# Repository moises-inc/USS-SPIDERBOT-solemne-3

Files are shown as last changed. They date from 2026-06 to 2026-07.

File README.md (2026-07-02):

# USS SpiderBot — Robot Cuadrúpedo de Reconocimiento y Rescate





**USS SpiderBot** es un prototipo de robot cuadrúpedo articulado de 4 grados de libertad (4-DoF) controlado de forma inalámbrica por una ESP32 y desarrollado bajo un modelo de programación asíncrona en **MicroPython**. El robot está diseñado para operar en entornos hostiles de búsqueda y rescate, detectando obstáculos e inestabilidades físicas de forma inteligente en el borde (Edge AI) y empleando una estructura cinemática simplificada y de bajo consumo.

---

<p align="center">
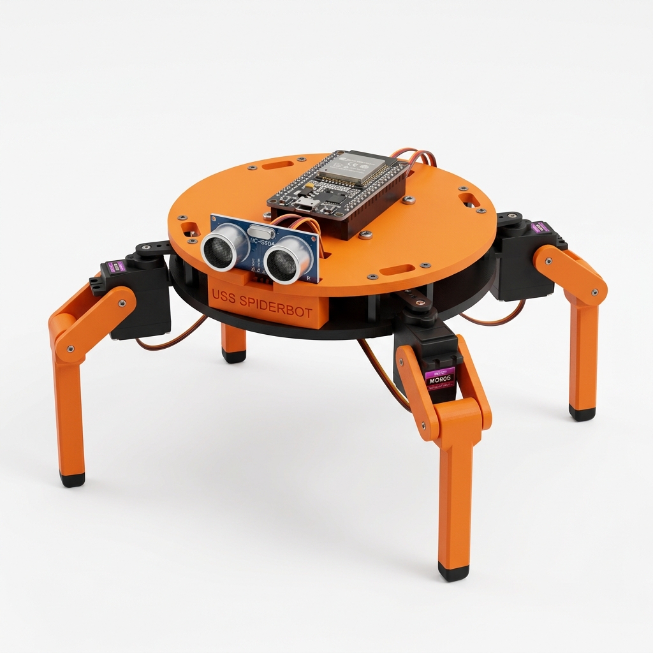
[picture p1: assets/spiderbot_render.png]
USS SpiderBot Render 3D
  
</p>

---

## 📄 Documentación y Entregables del Proyecto
Toda la fundamentación teórica, análisis físico y guías se encuentran compilados en formato PDF dentro del repositorio:
*   📚 **[Informe Técnico Final (PDF)](docs/informe_proyecto_spiderbot.pdf):** Documento formal con todo el desglose metodológico, cálculos de torque y diagramas.
*   📊 **[Presentación de Defensa Beamer (PDF)](docs/presentacion_hall_spiderbot.pdf):** Diapositivas oficiales preparadas para la exposición en el Hall de la Universidad.
*   📐 **[Guía de Modelado y CAD en OpenSCAD (PDF)](docs/guia_openscad.pdf):** Manual de desarrollo paramétrico de piezas e impresión 3D.
*   🛠️ **[Reporte de Diseño e Integración 3D (Markdown)](docs/reporte_evaluacion_diseno_3d.md):** Evaluación física y geométrica para el montaje de los nuevos componentes.

---

## 🛠️ Arquitectura de Hardware y Potencia (4-DoF Simplificada)
El diseño electrónico final prioriza la ligereza física y la eficiencia en el consumo de corriente, operando con una fuente de alimentación común estabilizada:

*   **Lógica de Control:** ESP32 DevKit V1 (38 pines) + IMU MPU6050 + Sensor de ultrasonido HC-SR04 + Zumbador activo de 5V (GPIO 14).
*   **Actuación:** 4 servomotores SG90 / MG90S conectados de forma directa a la ESP32 (sin multiplexor PCA9685).
*   **Alimentación Común Regulada (1x LM2596):**
    *   **Pack Baterías (2x 18650 Li-ion, 7.4V) ➔ LM2596 (Ajustado a 5.2V):** Un solo convertidor regulador que suministra 5.2V estables en paralelo tanto a la ESP32 (pin Vin) como a los rieles de potencia de los 4 servomotores de caderas.
    *   *Nota:* Para mitigar caídas de tensión (brownouts) por los picos de corriente, el firmware realiza un encendido secuencial espaciado por software.

### 📌 Mapa de Conexiones Físicas (Pinout)

| GPIO ESP32 | Componente | Tipo de Señal | Descripción |
| :--- | :--- | :--- | :--- |
| **GPIO 21** | MPU6050 (IMU) | SDA (I2C) | Bus de datos serie de la unidad inercial (100kHz). |
| **GPIO 22** | MPU6050 (IMU) | SCL (I2C) | Bus de reloj serie de la unidad inercial (100kHz). |
| **GPIO 18** | HC-SR04 (Sonar) | TRIGGER | Salida digital de pulso de disparo. |
| **GPIO 19** | HC-SR04 (Sonar) | ECHO | Entrada digital de pulso de retorno. |
| **GPIO 14** | Buzzer Activo | Salida Digital | Señal de alarma en caso de proximidad. |
| **GPIO 23** | Servo FR - Coxa | Salida PWM | Articulación cadera delantera derecha (Canal 0). |
| **GPIO 17** | Servo FL - Coxa | Salida PWM | Articulación cadera delantera izquierda (Canal 1). |
| **GPIO 15** | Servo RL - Coxa | Salida PWM | Articulación cadera trasera izquierda (Canal 2). |
| **GPIO 13** | Servo RR - Coxa | Salida PWM | Articulación cadera trasera derecha (Canal 3). |
| **Vin (ESP32)** | LM2596 Out | Alimentación | Tensión de entrada regulada (5.2V). |
| **GND (Unificado)** | Todo el sistema | Tierra común | Referencia negativa común unificada. |

---

## 🧠 Inteligencia Artificial Sensorial y Failsafe Embebido
El robot incorpora un módulo de Edge AI local en MicroPython ([classifier_ia.py](firmware/classifier_ia.py)) que procesa las firmas inerciales de la IMU para clasificar el estado dinámico del cuadrúpedo:

*   **`FALLEN` (Caída):** Se activa si la inclinación del eje Pitch o Roll supera los $\pm 45^\circ$, ante una caída libre (gravedad $|a| < 0.2g$) o choque violento ($|a| > 2g$). El lazo reactivo de control entra en *failsafe*: cancela la marcha, envía los servos a posición estática y emite un pitido de pánico intermitente.
*   **`PUSHED` (Perturbación):** Detecta empujones externos bruscos si la velocidad angular del giroscopio supera los $120^\circ/\text{s}$ mientras el robot está quieto.
*   **`SLIPPING` (Derrape):** Clasifica si el robot intenta caminar pero no experimenta la oscilación inercial periódica normal en su eje de avance (baja varianza en el acelerómetro horizontal).

---

## 💻 Servidor HTTP y Dashboard de Control Real
La ESP32 inicia un Access Point Wi-Fi (`USS_SpiderBot_AP`) y levanta un servidor HTTP asíncrono no bloqueante en el puerto 80.
*   **Servicio Web:** Sirve el archivo interactivo `dashboard.html` por bloques de 512 bytes para prevenir la fragmentación de la memoria RAM.
*   **Estética:** Diseño futurista en modo oscuro con *glassmorphic blur*, mandos de control D-pad, atajos de teclado completos (W, A, S, D, Espacio, R) y telemetría inercial en tiempo real representada en una retícula SVG activa.
*   **Failsafe de Conexión:** Si el navegador detecta la pérdida de la comunicación Wi-Fi por más de dos peticiones, bloquea automáticamente los mandos y despliega una pantalla de reconexión.

---

## 📂 Estructura del Repositorio

```text
├── cad/                  # Modelos paramétricos en OpenSCAD y STLs imprimibles
├── docs/                 # Documentos de LaTeX (Informe y Diapositivas) y PDFs
├── firmware/             # Código fuente en MicroPython para la ESP32
│   ├── index.html        # Dashboard versión Simulación/Demo
│   ├── dashboard.html    # Dashboard versión Pruebas Reales (Autónomo)
│   ├── web_server.py     # Servidor HTTP asíncrono y enrutador de API
│   ├── classifier_ia.py  # Clasificador embebido de IA Sensorial (Decision Tree)
│   ├── main.py           # Bucle de control asíncrono principal (Gait Control & Failsafe)
│   └── ...               # Módulos auxiliares de hardware (mpu6050, sonar, buzzer)
├── LICENSE               # Licencia de código abierto MIT
└── README.md             # Documentación principal de presentación
```

---

## ⚠️ Protocolo de Seguridad y Operación Eléctrica
Al realizar pruebas y depuraciones físicas:
1.  **Nunca enciendas el interruptor de las baterías si el cable micro-USB está conectado al PC**. Si alimentas por el pin `Vin` (vía LM2596) y mantienes conectado el USB simultáneamente, puedes dañar el puerto de tu computadora o la ESP32 por corriente de retorno.
2.  **Desconecta la línea Vin o mantén apagadas las baterías** si vas a cargar o depurar código por puerto USB.
3.  **Calibra siempre la salida del LM2596** con un multímetro a exactamente **5.2V** en vacío *antes* de conectarlo a la ESP32 y a los servomotores.

---

## 👥 Autores y Licencia
Este proyecto ha sido desarrollado por el Grupo de Trabajo de la Universidad San Sebastián (Puerto Montt, Chile - 2026).
Distribuido bajo la Licencia **MIT** (Consulte [LICENSE](LICENSE) para más detalles).

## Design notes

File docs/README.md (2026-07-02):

# USS SpiderBot — Wiki Técnica de Código

Bienvenido a la wiki técnica del **USS SpiderBot**, un robot caminador cuadrúpedo simplificado de **4 grados de libertad (4-DoF)** desarrollado para la asignatura de **Taller de Programación I (Universidad San Sebastián)**. 

Este robot ha sido diseñado con estabilidad inercial activa para desplazarse de forma segura sobre terrenos rugosos o inclinados, prevención reactiva de colisiones frontales y un panel de control remoto web asíncrono y offline accesible desde cualquier navegador. Las rodillas se fijan mecánicamente a 90°, reduciendo la complejidad eléctrica y de firmware sin sacrificar la marcha de gateo funcional.

---

## 🚀 Stack Tecnológico

El proyecto integra tecnologías de hardware embebido, desarrollo web nativo y modelado tridimensional paramétrico:

*   **Microcontrolador principal:** ESP32 DevKit V1 (38 pines) ejecutando **MicroPython v1.20+**.
*   **Locomoción y multitarea:** Concurrencia cooperativa no bloqueante mediante la librería estándar **`uasyncio` (asyncio)** de MicroPython.
*   **Actuadores:** 4x Servomotores analógicos SG90/MG90S (solo caderas) controlados directamente mediante señales PWM por pines GPIO de la ESP32, sin multiplexor PCA9685. Las rodillas se fijan mecánicamente a 90°.
*   **Sensores:**
    *   Unidad de Medida Inercial (IMU) **MPU6050** de 6 ejes para el cálculo dinámico de inclinación (Pitch y Roll).
    *   Sensor ultrasónico de distancia **HC-SR04** para evasión de obstáculos.
*   **Interfaz de Control Remoto:** Servidor HTTP embebido asíncrono en socket TCP (puerto 80) que sirve un Dashboard web en HTML5, CSS3 Glassmorphism y Vanilla JavaScript (sin CDNs, 100% offline).
*   **Modelado 3D Estructural:** Piezas paramétricas imprimibles en FDM modeladas íntegramente en **OpenSCAD**.

---

## 📚 Tabla de Contenidos de la Wiki

Navega a través de las secciones de documentación técnica de este repositorio:

1.  **[Arquitectura General e Inferencia de Postura](ARCHITECTURE.md):** Conoce el flujo de ejecución asíncrono, la teoría de la marcha de gateo (Crawl Gait) para 4 caderas y la lógica matemática de la estabilización inercial activa.
2.  **[Diccionario de Componentes y Módulos](MODULES.md):** Detalle de cada archivo de código fuente, sus responsabilidades, funciones principales, variables físicas y dependencias internas de importación.
3.  **[Guía de Impresión 3D y Creality Print](guia_impresion_3d.md):** Parámetros de laminación (infill, perfiles de PLA/PETG, recuentos de pared) y distribución de piezas por platos de impresión en la cama.
4.  **[Guía Completa de OpenSCAD: Del Cubo al Robot Cuadrúpedo](guia_openscad.md):** Tutorial exhaustivo de OpenSCAD desde cero usando el SpiderBot como caso de estudio real, con ejemplos funcionales extraídos de `cad/`.
5.  **[Informe Técnico Final (TeX)](informe_proyecto_spiderbot.tex) / [PDF Compilado](informe_proyecto_spiderbot.pdf):** Documento académico final del proyecto SpiderBot (evaluación Solemne 3), cubriendo diseño mecánico, electrónica, firmware multitarea y simulación.
6.  **[Presentación del Hall (TeX)](presentacion_hall_spiderbot.tex) / [PDF Compilado](presentacion_hall_spiderbot.pdf):** Diapositivas académicas de apoyo visual diseñadas en LaTeX Beamer para exhibición en el hall de la universidad.

---

*Desarrollado en la Universidad San Sebastián. Año 2026.*

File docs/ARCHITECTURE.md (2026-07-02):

# Arquitectura General y Flujos — USS SpiderBot

Esta sección describe la arquitectura lógica del firmware, el flujo de procesamiento de señales en paralelo, las modalidades adaptativas para simulación en Wokwi y los patrones de diseño de software aplicados.

---

## 1. Diagrama de Bloques de la Arquitectura (Mermaid.js)

El firmware utiliza la concurrencia asíncrona cooperativa en MicroPython. Tres corrutinas corren de forma concurrente, comunicándose a través de un registro de estado centralizado. 

### Ejecución Adaptativa (Detección del Entorno)
El sistema detecta automáticamente si se encuentra en el robot físico o en Wokwi escaneando las redes Wi-Fi locales en busca de la red virtual `"Wokwi-GUEST"`:
1.  **Modo Hardware Real:** Configura el Wi-Fi como **Access Point (AP)** privado (`USS_SpiderBot_AP`) y realiza lecturas de la IMU física MPU6050 a través de I2C a 100kHz. Los 4 servos de cadera son comandados directamente por GPIOs (23, 17, 15, 13) a través de `ESP32ServoDirect`.
2.  **Modo Simulación:** Configura el Wi-Fi como **Estación (STA)** conectándose a `Wokwi-GUEST` para permitir el acceso al simulador. Los servos son controlados con los mismos pines GPIO a través del generador PWM directo.

```mermaid
graph TD
    %% Clientes de Red (Exteriores)
    subgraph Dispositivos Clientes
        A[Laptop A - Dashboard UI]
        B[Laptop B - Motor de IA]
    end

    %% Servidor y Registro de Estado (ESP32)
    subgraph Firmware Embebido ESP32
        C[web_server.py - Servidor HTTP]
        D[state.py - Registro Global Compartido]
        E[main.py - Tarea Locomoción]
        F[main.py - Tarea Sensores 20Hz]
    end

    %% Actuación (4-DoF: solo caderas)
    G[ESP32ServoDirect - Controlador 4 Servos GPIO]

    %% Sensores e Interfaces de Red
    subgraph Sensores e interfaces
        H[MPU6050 - IMU Inercial I2C 100kHz]
        I[HC-SR04 - Sonar Ultrasonido]
        J1[AP Wi-Fi Local - Físico]
        J2[Wokwi-GUEST - Wi-Fi Virtual]
    end

    %% Flujos de Red
    A <-->|HTTP GET/POST /telemetry| C
    B -->|HTTP GET /api/control?cmd=...| C
    C <-->|Lee/Escribe Estado| D
    E <-->|Monitorea comando / actualiza| D
    F <-->|Escribe Pitch/Roll/Distancia/Estado IA| D
    
    %% Ruta de Wi-Fi según entorno
    C <-->|Modo AP| J1
    C <-->|Modo STA| J2
    
    %% Acciones de Hardware/Simulación (4-DoF)
    E -->|Fórmula Gait + Compensación| G
    G -->|4x PWM a 50Hz| J3[4x Servomotores SG90/MG90S<br/>Solo Caderas - Rodillas fijas 90°]
    F -->|Lectura I2C 100kHz| H
    F -->|Lectura GPIO Pulso 5ms timeout| I
    F -->|Clasifica estado| K[classifier_ia.py<br/>Decision Tree]
    K -->|FALLEN/PUSHED/SLIPPING/NORMAL| D
```

---

## 2. Flujo de Datos Global (Request-Response & Control Loop)

La información fluye a través del sistema mediante un modelo desacoplado por estado:

1.  **Lectura Frecuente (Lazo de Entrada):** La tarea asíncrona `sensor_updater()` corre de forma continua cada 50ms (20Hz). Lee los datos brutos del sensor ultrasónico (con timeout de 5ms y backoff adaptativo a 0.5Hz tras 5 fallos consecutivos) y de la IMU MPU6050 por I2C a 100kHz. Actualiza `state.pitch_actual`, `state.roll_actual`, `state.distancia_actual` y `state.estado_ia` (clasificado por el Decision Tree de `classifier_ia.py`) en el módulo [state.py](file:///mnt/9b846436-0407-4e80-b8af-5417ffbdee8e/Github/USS%20SPIDERBOT%20(solemne%203)/firmware/state.py).
2.  **Peticiones del Operador (Entrada por Red):** Cuando el usuario interactúa con la página web o un modelo de IA en la laptop, se envía una petición Fetch a `/api/control?cmd=forward`.
3.  **Procesamiento HTTP (Asíncrono con GC Lazy):** El servidor HTTP asíncrono en `web_server.py` procesa la petición de forma no bloqueante y escribe el comando en `state.comando_actual`. Tras enviar la respuesta, ejecuta `gc.collect()` solo si la memoria RAM libre es inferior a 15KB (`gc.mem_free() < 15000`), desplazando la recolección de basura a segundo plano y minimizando la latencia de respuesta.
4.  **Bucle de Decisión y Control (Locomoción):** La corrutina `locomotion_loop()` en `main.py` vigila permanentemente el estado de las variables físicas y los comandos:
    *   **Prioridad 1 (Detección de Caída por IA):** Si `state.estado_ia == "FALLEN"`, la corrutina detiene la marcha inmediatamente, emite alerta acústica de postura y fuerza `state.comando_actual = "stop"`.
    *   **Prioridad 2 (Freno de Emergencia):** Si `state.distancia_actual < 15.0`, la corrutina detiene inmediatamente la marcha, emite alertas sonoras con el Buzzer y fuerza `state.comando_actual = "stop"`.
    *   **Prioridad 3 (Locomoción):** Si el comando es `"forward"`, ejecuta un paso de la caminata de gateo (Crawl Gait) interpolando las 4 caderas.
    *   **Prioridad 4 (Estabilización Dinámica):** Al mover las articulaciones, se consultan `state.pitch_actual` y `state.roll_actual` para calcular y aplicar en tiempo real correcciones angulares sobre las caderas en apoyo, manteniendo estable el chasis.

---

## 3. Patrones de Diseño de Software Aplicados

*   **Multitarea Cooperativa (Cooperative Multitasking):** Implementada a través del bucle de eventos asíncrono de `uasyncio`. En lugar de utilizar retardos bloqueantes (`time.sleep_ms`) o hilos físicos del procesador (que consumen demasiados recursos de memoria y son inestables en MicroPython), las tareas liberan la CPU cediéndola voluntariamente a otras mediante `await asyncio.sleep_ms()`.
*   **Patrón Shared Registry (Estado Singleton):** Centralizado en [state.py](file:///mnt/9b846436-0407-4e80-b8af-5417ffbdee8e/Github/USS%20SPIDERBOT%20(solemne%203)/firmware/state.py). Permite desacoplar por completo la ejecución física de los servomotores de las peticiones de red del servidor HTTP, solucionando la importación circular de módulos.
*   **Control Reactivo Proporcional (P-Control):** La estabilización inercial activa calcula la corrección mediante un factor de escala estático multiplicativo respecto a la desviación angular ($\Delta \text{Ángulo} \times \text{Factor}$). Esto imita la lógica básica de control proporcional industrial, brindando respuestas inmediatas y suaves sin sobrecarga matemática.
*   **Abstracción de Control Directo (Hardware/Simulador):** La clase `ESP32ServoDirect` unifica la interfaz de control de los servomotores a través del método `.set_servo_angle()`. Esta capa oculta la modulación PWM nativa de 16 bits de MicroPython (`duty_u16`), permitiendo que el algoritmo de locomoción opere con los mismos comandos y mapeos físicos tanto en el simulador Wokwi como en el hardware real.
*   **Recolección de Basura Diferida (GC Lazy):** Implementado en `web_server.py`. La GC se ejecuta solo si la memoria libre baja de 15KB (`gc.mem_free() < 15000`) tras servir la respuesta HTTP. Esto evita pausas de latencia impredecibles durante la marcha o la telemetría.
*   **Backoff Adaptativo de Sonar:** El lazo `sensor_updater()` en `main.py` reduce la frecuencia de lectura del HC-SR04 de 20Hz a 0.5Hz (cada 40 ciclos) si se producen 5 timeouts consecutivos del sensor (5ms por pulso), evitando el bloqueo prolongado de la CPU por fallos del hardware.

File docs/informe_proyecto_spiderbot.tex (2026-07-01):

% =============================================================================
% Informe Técnico Final: USS SpiderBot — Robot Cuadrúpedo de Reconocimiento
% Taller de Programación I, Universidad San Sebastián. Año 2026.
% Compilar con: xelatex informe_proyecto_spiderbot.tex
% =============================================================================
\documentclass[12pt]{article}

% --- Paquetes Básicos ---
\usepackage{fontspec}
\usepackage[spanish,es-noshorthands,es-noquoting]{babel}
\usepackage{geometry}
\geometry{a4paper, margin=2.5cm} % Márgenes estándar según norma USS
\usepackage{setspace}
\setstretch{1.5} % Interlineado 1.5 según norma USS
\usepackage{graphicx}
\usepackage{booktabs}  % Para tablas formato APA
\usepackage{tabularx}

% --- Paquetes Matemáticos y de Símbolos ---
\usepackage{amsmath}   % Esencial para fórmulas avanzadas
\usepackage{amssymb}   % Para símbolos
\usepackage{textcomp}  % Para manejar símbolos de texto

% --- Paquetes de Formato y Enlaces ---
\usepackage{hyperref}  
\hypersetup{
    colorlinks=true,   % True: colorea el texto del link
    urlcolor=blue,     % Color para los enlaces web externos (formato APA estándar)
    linkcolor=black,   % Color para los enlaces internos (como el índice)
    citecolor=black    % Color para las citas bibliográficas
}
\usepackage{titlesec}
\usepackage{xcolor}
\usepackage{xurl} % Permite romper las URLs en cualquier carácter
\usepackage{listings}

% --- Configuración de Títulos ---
\titleformat{\section}{\normalfont\Large\bfseries}{\thesection}{1em}{}
\titleformat{\subsection}{\normalfont\large\bfseries}{\thesubsection}{1em}{}
\titleformat{\subsubsection}{\normalfont\normalsize\bfseries}{\thesubsubsection}{1em}{}

\newcommand{\codigo}[1]{\texttt{#1}}

\begin{document}

% ======================================================
% PORTADA
% ======================================================
\begin{titlepage}
    \centering
    {\bfseries\LARGE Universidad San Sebastián \par}
    \vspace{1cm}
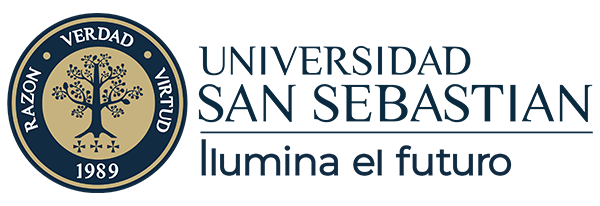
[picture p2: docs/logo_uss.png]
     \\
    \vspace{1cm}
    {\scshape\Large Facultad de Ingeniería y Tecnología \par}
    {\large Carrera de Ingeniería Civil Informática \par}
    \vspace{1.5cm}
    {\bfseries\huge Informe Técnico Final: \par}
    {\Large USS SpiderBot --- Robot Cuadrúpedo de Reconocimiento \par}
    \vspace{2cm}
    
    {\large \textbf{Integrantes y Roles:} \par}
    \begin{tabular}{ll}
        Moisés Amundarain & Integración y Firmware Asíncrono \\
        Camila Aravena & Diseño 3D en OpenSCAD y Tolerancias \\
        Fernando Ramírez & Configuración Electrónica y Potencia \\
        Juan Pablo Vargas & Simulación Wokwi y Calibración IMU \\
        María José Santander & Dashboard Web Embebido e Interfaz SVG \\
    \end{tabular}
    \vfill
    {\large Puerto Montt, Chile \par}
    {\large 1 de Julio de 2026 \par}
\end{titlepage}

% ======================================================
% ÍNDICE
% ======================================================
\newpage
\tableofcontents
\newpage

% ======================================================
% 1. IDENTIFICACIÓN DEL GRUPO
% ======================================================
\section{Identificación del Grupo}
\begin{table}[h!]
\centering
\begin{tabular}{p{5cm}p{10cm}}
\toprule
\textbf{Parámetro} & \textbf{Detalle} \\
\midrule
Asignatura & Taller de Programación I \\
Evaluación & Solemne 3 \\
Microcontrolador & ESP32 DevKit V1 \\
Lenguaje & MicroPython (v1.20+) \\
Integrante 1 & Moisés Amundarain — [Integración y Firmware Asíncrono] \\
Integrante 2 & Camila Aravena — [Diseño 3D en OpenSCAD y Tolerancias] \\
Integrante 3 & Fernando Ramírez — [Configuración Electrónica y Potencia] \\
Integrante 4 & Juan Pablo Vargas — [Simulación Wokwi y Calibración IMU] \\
Integrante 5 & María José Santander — [Dashboard Web Embebido e Interfaz SVG] \\
Fecha & 1 de Julio de 2026 \\
\bottomrule
\end{tabular}
\end{table}

% ======================================================
% 2. DESCRIPCIÓN DEL SISTEMA
% ======================================================
\section{Descripción del Sistema}
El proyecto \textbf{USS SpiderBot} consiste en el diseño, modelado mecánico, desarrollo de hardware y arquitectura de software de un robot caminador cuadrúpedo de 4 grados de libertad (4-DoF) con rodillas rígidas. El sistema ha sido diseñado específicamente para la exploración autónoma o asistida y el reconocimiento de entornos hostiles o zonas de desastre colapsadas por escombros, donde la locomoción tradicional por ruedas u orugas resulta ineficaz.

El robot opera de manera asíncrona mediante un firmware multitarea cooperativo no bloqueante que corre sobre una placa ESP32 DevKit V1. Implementa una marcha secuencial de gateo oscilante de caderas (Crawl Gait) y utiliza un sensor inercial inteligente para identificar inestabilidades, caídas dinámicas y empujones externos en tiempo real, garantizando la detección autónoma de accidentes en campo. Adicionalmente, cuenta con evasión reactiva de obstáculos frontal por sensor ultrasónico y expone un servidor HTTP nativo con un Dashboard web interactivo para telemetría vectorial y mando manual.

\subsection{Funciones principales que cumple el sistema:}
\begin{itemize}
    \item \textbf{Monitoreo Inercial Continuo:} Medición de los ángulos de inclinación (Pitch y Roll) mediante la IMU MPU6050 a una frecuencia de refresco de $20\text{ Hz}$.
    \item \textbf{Clasificación de Inteligencia Artificial Sensorial:} Monitoreo y diagnóstico local de inestabilidades dinámicas, caídas físicas (failsafe automático) y empujones externos mediante un árbol de decisión embebido.
    \item \textbf{Locomoción Secuencial Estable (Crawl Gait):} Desplazamiento del cuerpo manteniendo en todo momento al menos tres extremidades en contacto para asegurar que el centro de masa resida dentro del polígono de sustentación.
    \item \textbf{Evasión Reactiva de Obstáculos:} Detección de proximidad frontal mediante sensor HC-SR04. Ante lecturas inferiores a $15\text{ cm}$, se cancela de forma inmediata la locomoción ($<25\text{ ms}$), se activa una alarma sonora mediante el buzzer y se retorna a pose segura.
    \item \textbf{Control y Telemetría Remota Web:} Servidor web asíncrono que expone una consola de control remota en CSS Glassmorphism y JS nativo, con actualización de telemetría y renderizado vectorial de inclinación SVG.
\end{itemize}

\newpage

% ======================================================
% 3. DISEÑO MECÁNICO Y ESTRUCTURAL (OPENSCAD)
% ======================================================
\section{Diseño Mecánico y Estructural (OpenSCAD)}
El modelado tridimensional de las piezas se realizó de forma paramétrica en OpenSCAD utilizando el paradigma de geometría sólida constructiva (CSG).

\subsection{Estructura del Chasis (Doble Deck)}
El cuerpo central del robot consta de un sistema de doble placa circular (doble deck) que aísla los componentes de potencia y cableado del plano de los sensores y control:
\begin{itemize}
    \item \textbf{Placa Inferior:} Cilindro plano de radio $r = 65\text{ mm}$ y espesor $t = 3\text{ mm}$ que aloja perimetralmente los 4 brackets de fijación de servos de cadera. Cuenta con ranuras pasantes para la fijación de la batería mediante correas de velcro.
    \item \textbf{Placa Superior:} Placa de protección que se acopla a la inferior mediante 4 pilares espaciadores M3 de $19\text{ mm}$ de alto. Incorpora una cuna central de dimensiones $84\text{ x }56\text{ x }3\text{ mm}$ para alojar a presión la protoboard de 400 puntos, una cuna trasera para el regulador XL6009E1 y 4 agujeros de $14\text{ mm}$ de diámetro para el ruteo de cables.
    \item \textbf{Soporte HC-SR04:} Soporte vertical de $2\text{ mm}$ de espesor con dos orificios de $16.5\text{ mm}$ de diámetro espaciados a $26\text{ mm}$ entre centros, reforzado por dos gussets triangulares laterales para resistir fuerzas de cizalladura inerciales en caso de impacto.
\end{itemize}

\begin{figure}[htbp]
    \centering
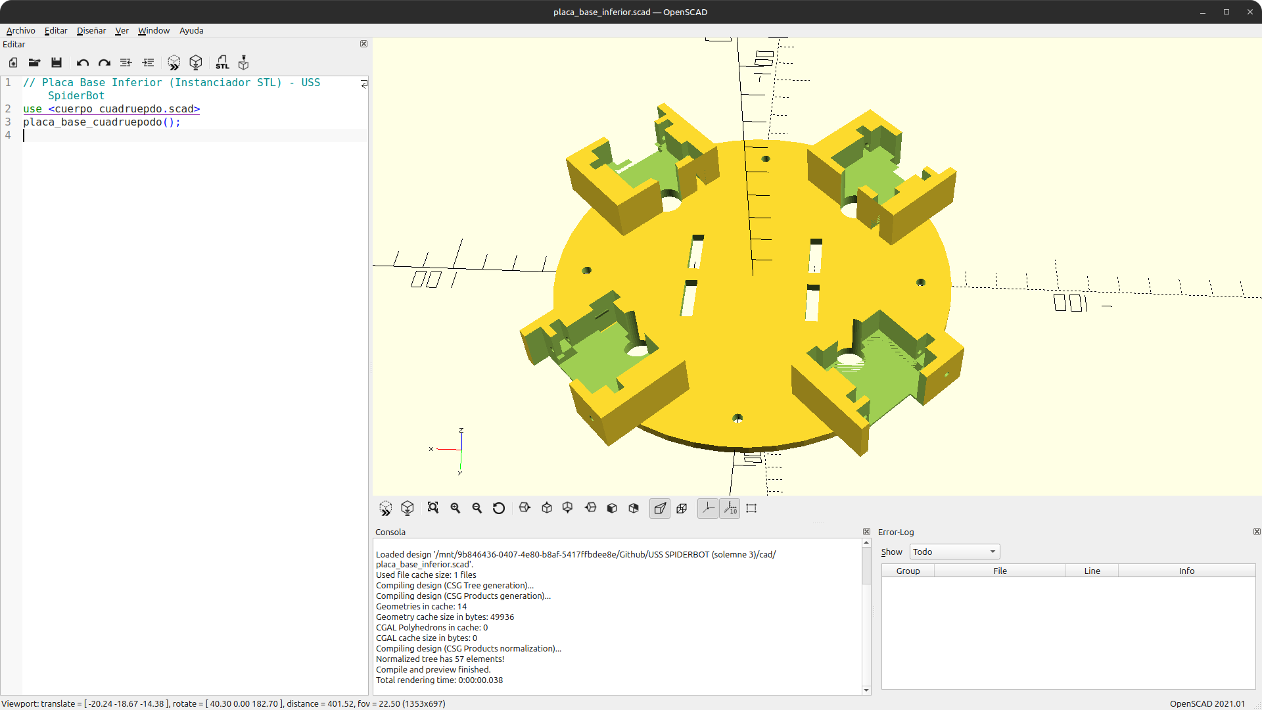
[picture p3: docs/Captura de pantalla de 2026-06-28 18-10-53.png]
    
    \hfill
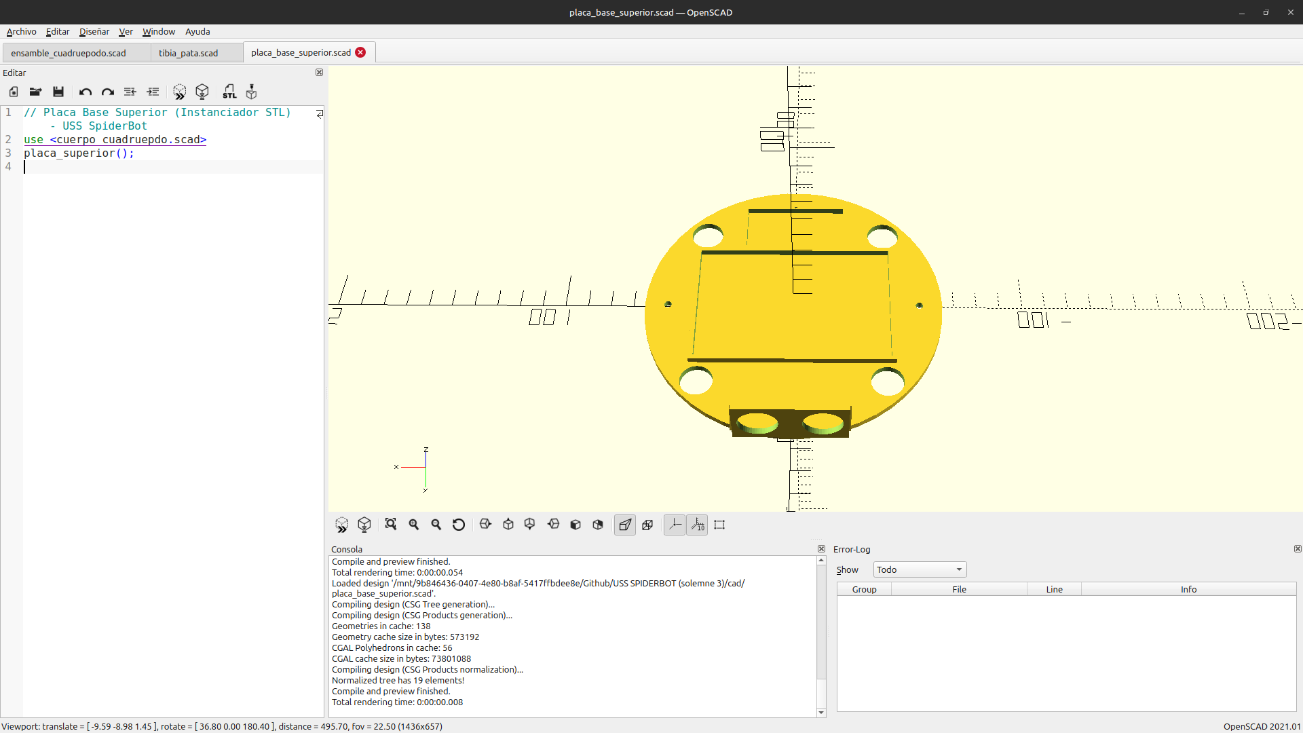
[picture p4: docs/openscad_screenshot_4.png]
    
    \caption{Modelado paramétrico en OpenSCAD de la placa base inferior (izquierda) y placa base superior (derecha).}
    \label{fig:placas_chasis}
\end{figure}

\begin{figure}[htbp]
    \centering
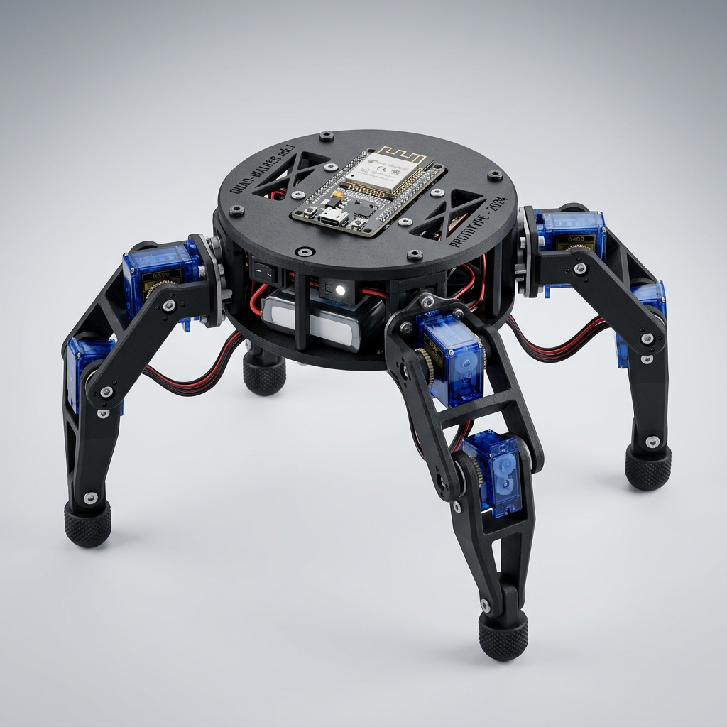
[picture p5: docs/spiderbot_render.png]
    
    \caption{Renderizado 3D paramétrico del chasis final y las extremidades articuladas del USS SpiderBot.}
    \label{fig:spiderbot_render}
\end{figure}

\subsection{Articulaciones y Extremidades (Fémur y Tibia)}
La configuración de 4-DoF del robot simplifica las extremidades eliminando el servomotor de rodilla. Las uniones fémur-tibia están bloqueadas rígidamente a 90 grados, reduciendo la masa móvil y el número de cables.
\begin{itemize}
    \item \textbf{Fémur:} Brazo de articulación de $55\text{ mm}$ de longitud entre centros. Une la corona del servo de cadera con la tibia de forma rígida. Se utilizó la función \codigo{hull()} para conectar suavemente la corona cilíndrica con la cavidad prismática del servo de rodilla (bloqueado), optimizando la distribución de masa y la resistencia a la flexión.
    \item \textbf{Tibia:} Pierna inferior curva con una longitud vertical de $65\text{ mm}$ y pie semiesférico de radio $r = 5.5\text{ mm}$. La curvatura estructural del modelo aumenta el despeje libre sobre el suelo y distribuye las fuerzas de reacción del impacto del pie en la marcha.
\end{itemize}

\begin{figure}[htbp]
    \centering
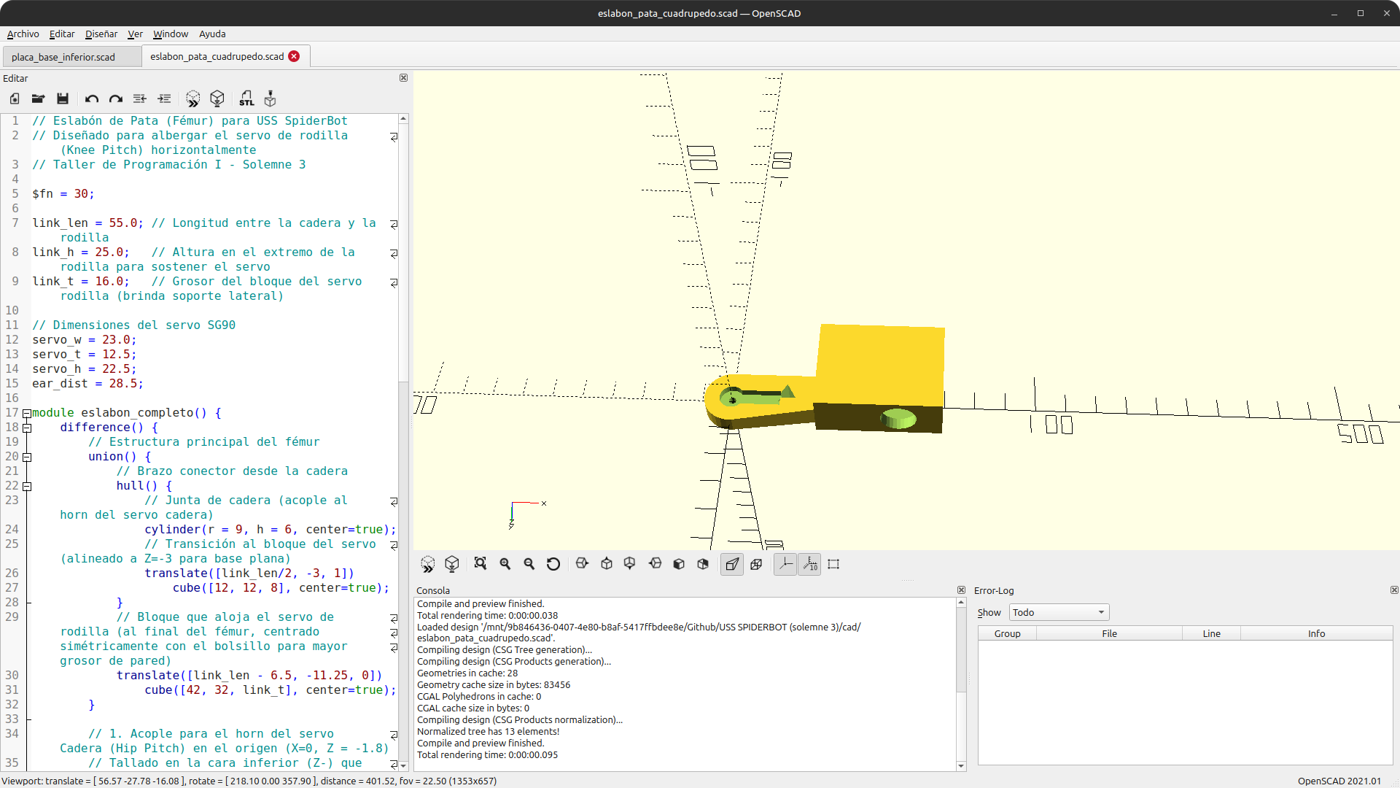
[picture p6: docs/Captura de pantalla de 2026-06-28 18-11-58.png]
    
    \hfill
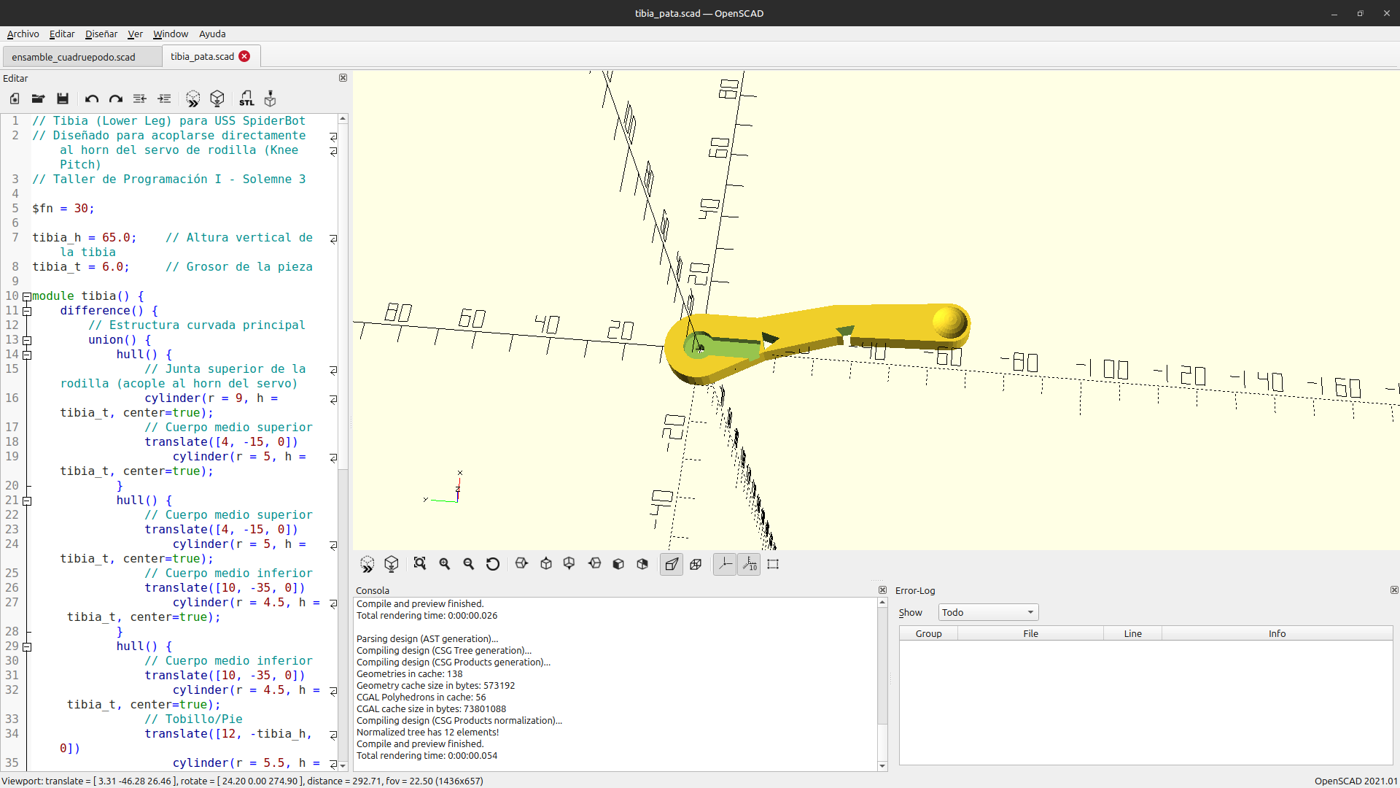
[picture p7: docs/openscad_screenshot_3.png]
    
    \caption{Modelado en OpenSCAD del eslabón fémur (izquierda) y de la tibia articulada curva (derecha).}
    \label{fig:femur_tibia_scad}
\end{figure}

\newpage

\subsection{Precisión en Tolerancias e Interfaces Mecánicas}
\subsubsection{Cavidades de Servomotores (Snug Fit)}
Debido a la contracción del plástico durante el enfriamiento de la extrusión FDM, se definió una tolerancia de precisión de \textbf{$0.3\text{ mm}$ totales} ($0.15\text{ mm}$ por lado) para las cavidades de los servos SG90/MG90S. Sus dimensiones internas se establecieron en $24.2\text{ x }23.2\text{ x }13.4\text{ mm}$, logrando un ajuste a presión sin juego mecánico. Las ranuras de las bridas se fijaron a $2.8\text{ mm}$ de ancho y los agujeros de roscado de tornillos M2 a $2.0\text{ mm}$ de diámetro.

\subsubsection{Bolsillos de Doble Profundidad (Dual-Depth Pocket)}
Para evitar el estrangulamiento de los cables de salida en la base del servo, se implementaron bolsillos de doble profundidad:
\begin{equation}
    D(z) = 
    \begin{cases} 
      30.0\text{ mm} & \text{si } z \le 5.0\text{ mm} \quad \text{(Espacio para cables)} \\
      25.0\text{ mm} & \text{si } z > 5.0\text{ mm} \quad \text{(Ajuste del cuerpo)}
   \end{cases}
\end{equation}
Esto garantiza que los tornillos autorroscantes M2 plásticos agarren sobre plástico 100\% macizo de los brackets a $X = \pm 14.25\text{ mm}$.

\newpage

\subsubsection{Cerraduras de Acople Horn (Single-Arm Horn Locks)}
Para eliminar las pérdidas de transmisión por rozamiento o juego entre los acoples, se diseñaron chaveteros de un brazo (\textit{single-arm horn locks}) embutidos en las caras de acople mecánico del fémur y la tibia, bloqueando mecánicamente el brazo del horn estriado original del servo en el sólido de plástico.

% ======================================================
% 4. LISTA DE MATERIALES
% ======================================================
\section{Lista de Materiales}
La Tabla 2 describe la lista de materiales completa requerida para ensamblar e implementar el prototipo del robot caminador:

\begin{table}[htbp]
\centering
\caption{BOM (Bill of Materials) del USS SpiderBot}
\vspace{0.3cm}
\begin{tabularx}{\textwidth}{c l X}
\toprule
\textbf{Cant.} & \textbf{Componente / Material} & \textbf{Descripción / Especificación} \\
\midrule
1 & ESP32 DevKit V1 (38 pines) & Microcontrolador principal con soporte WiFi y MicroPython \\
1 & Protoboard (400 puntos) & Base para montaje y ruteo común de señales \\
4 & Servomotores SG90 / MG90S & Servos analógicos de torque (Coxa en las 4 patas, rodilla rígida) \\
1 & IMU MPU6050 (GY-521) & Unidad de medida inercial (giroscopio y acelerómetro) \\
1 & Sensor ultrasónico HC-SR04 & Sensor de distancia frontal para evasión de colisiones \\
1 & Buzzer Activo 5V & Dispositivo de alarma acústica por cercanía \\
1 & Convertidor Step-down LM2596 & Regulador de potencia ajustable regulado a 5.0V para alimentar la ESP32, sensores y servomotores en paralelo \\
1 & Porta Pilas Dual 2x18650 (2 celdas Li-ion) & Un único pack de 2x18650 proveyendo 7.4V de entrada al regulador \\
1 & Regulador Boost XL6009E1 & Elevador opcional para voltajes de batería bajos \\
s/n & Cables Dupont M-M y M-H & Cables de conexión para el bus I2C y GPIOs \\
\bottomrule
\end{tabularx}
\end{table}

% ======================================================
% 5. TABLA DE CONEXIONES (PINOUT)
% ======================================================
\section{Tabla de Conexiones (Pinout)}
El bus físico I2C de la ESP32 se utiliza de forma exclusiva para la IMU MPU6050. Los 8 servomotores se conectan directamente a pines GPIO con PWM de la ESP32, mientras que el sonar HC-SR04 y el buzzer activo se rutean a GPIOs digitales específicos:

\begin{table}[htbp]
\centering
\caption{Mapa de Conexiones Físicas de la ESP32}
\vspace{0.3cm}
\begin{tabularx}{\textwidth}{p{2.8cm} p{2.8cm} p{2.4cm} X}
\toprule
\textbf{GPIO ESP32} & \textbf{Componente} & \textbf{Tipo de Señal} & \textbf{Descripción} \\
\midrule
GPIO 21 & MPU6050 (IMU) & SDA (I2C) & Bus de datos serie de la unidad inercial \\
GPIO 22 & MPU6050 (IMU) & SCL (I2C) & Bus de reloj serie de la unidad inercial \\
GPIO 18 & HC-SR04 & TRIGGER & Salida digital de pulso de disparo del sonar \\
GPIO 19 & HC-SR04 & ECHO & Entrada digital de pulso de retorno del sonar \\
GPIO 14 & Buzzer Activo & Salida Digital & Señal de alarma en caso de proximidad \\
GPIO 23, 17, 15, 13 & Servos Coxa & Salida PWM & Control de cadera (FR, FL, RL, RR) \\
Vin (ESP32) & LM2596 Out & Alimentación & Tensión de entrada regulada (5.0V) \\
3.3V (ESP32) & MPU6050 (IMU) & Alimentación & Tensión lógica para sensor inercial \\
GND (Unificado) & Todo el sistema & Tierra común & Referencia negativa unificada \\
\bottomrule
\end{tabularx}
\end{table}

\newpage

Los picos de corriente transitorios que ocurren al iniciar la marcha del cuadrúpedo pueden generar caídas bruscas en la tensión lógica de alimentación (\textit{brownouts}), reiniciando la ESP32. Al reducir los servos a 4 unidades, el consumo de corriente total disminuye considerablemente, permitiendo simplificar la electrónica a un único convertidor reductor \textbf{LM2596} y un solo pack de baterías 18650. 

El LM2596 se regula a exactamente \textbf{5.0V} y alimenta tanto la ESP32 (pin Vin) como los sensores (HC-SR04, MPU6050, Buzzer) y los 4 servomotores de cadera en paralelo. Es fundamental unificar todas las referencias de tierra (\textbf{GND}) en un nodo común para evitar derivas de voltaje y lecturas corruptas en los sensores.

\subsection{Clasificador de IA Sensorial Embebida (\codigo{classifier\_ia.py})}
Para dotar al robot de capacidad de reacción autónoma ante eventos físicos no programados en la coreografía de locomoción, se implementó un clasificador ligero basado en árbol de decisión que ejecuta directamente en la ESP32 a $20\text{ Hz}$.

El módulo \codigo{classifier\_ia.py} define la clase \codigo{IASensorClassifier} que evalúa los valores brutos del acelerómetro y el giroscopio del MPU6050 junto con el comando de movimiento actual, retornando uno de cuatro estados posibles:

\begin{itemize}
    \item \textbf{FALLEN (Caída):} Se activa si la inclinación calculada (Pitch o Roll) supera los $\pm 45^\circ$, si la magnitud de aceleración resulta cercana a cero (caída libre, $|a| < 0.2g$), o si se detecta un impacto de choque superior a $2.0g$.
    \item \textbf{PUSHED (Perturbación):} Se detecta cuando el robot está en reposo (comando \texttt{stop} o \texttt{reposo}) pero la magnitud del giroscopio supera los $120^\circ/\text{s}$, indicando un empuje físico externo.
    \item \textbf{SLIPPING (Derrape):} Se identifica cuando el robot ejecuta una marcha (\texttt{forward} o \texttt{backward}) pero la varianza de la aceleración longitudinal es anormalmente baja, indicando que las patas se mueven en vacío sin desplazar el chasis.
    \item \textbf{NORMAL:} Estado por defecto cuando no se cumple ninguna condición anterior.
\end{itemize}

Los umbrales del clasificador se calibraron experimentalmente:
\begin{align*}
    \text{Pitch}_{\text{límite}} &= 45^\circ, \quad
    \text{Roll}_{\text{límite}} = 45^\circ, \quad
    a_{\text{caída libre}} < 0.2g \\
    a_{\text{impacto}} &> 2.0g, \quad
    \omega_{\text{perturbación}} > 120^\circ/\text{s}, \quad
    \sigma^2_{a_x, \text{derrape}} < 0.08
\end{align*}

En el bucle de control \codigo{locomotion\_loop()}, si \codigo{state.estado\_ia == "FALLEN"}, se detiene inmediatamente la marcha de gateo, los servos retornan a pose estática y el buzzer emite un sonido pulsante de emergencia. El estado clasificado se transmite también al dashboard web vía el campo \codigo{estado\_ia} en la API \texttt{/telemetry}, donde se despliega con código de colores dinámico.

\newpage

% ======================================================
% 6. FUNCIONES DEFINIDAS EN EL CÓDIGO
% ======================================================
\section{Funciones Definidas en el Código}
El firmware principal `main.py` implementa el paradigma asíncrono y modular. A continuación se desglosan las principales funciones y corrutinas que estructuran el firmware:

\begin{table}[htbp]
\centering
\caption{Funciones y Corrutinas de main.py}
\vspace{0.3cm}
\begin{tabularx}{\textwidth}{l >{\raggedright\arraybackslash}p{4.5cm} >{\raggedright\arraybackslash}X}
\toprule
\textbf{Función} & \textbf{Parámetros / Retorno} & \textbf{Descripción} \\
\midrule
\codigo{pos\_reposo()} & Sin parámetros / Sin retorno & Envía todos los servomotores de cadera a sus ángulos estáticos de reposo (90 grados). \\
\codigo{establecer\_angulo\_pata()} & \codigo{idx, c\_ang, f\_ang=90} / Sin retorno & Aplica límites físicos de seguridad, escribe directamente en los pines PWM de la ESP32 para controlar la cadera. \\
\codigo{mover\_suave\_ciclo()} & \codigo{c\_t, f\_t=None, pasos, delay} / async & Realiza interpolación lineal entre la posición actual de las caderas y sus objetivos para evitar tirones. \\
\codigo{caminar\_adelante()} & async / Sin retorno & Ejecuta la secuencia Crawl Gait de 4 caderas llamando a \codigo{mover\_suave\_ciclo()}. \\
\codigo{sensor\_updater()} & async / Corrutina cíclica & Adquiere los datos de aceleración y giroscopio de la IMU MPU6050 y la distancia del sensor HC-SR04 cada 50 ms. \\
\codigo{locomotion\_loop()} & async / Corrutina cíclica & Evalúa los comandos de marcha y supervisa los eventos críticos de seguridad (obstáculos y caídas detectadas por la IA). \\
\codigo{main\_async()} & async / Punto de entrada & Registra las tareas asíncronas de telemetría, locomoción, comandos y servidor web en el planificador asíncrono. \\
\bottomrule
\end{tabularx}
\end{table}

\newpage

% ======================================================
% 7. DIAGRAMA DE FLUJO — LÓGICA PRINCIPAL
% ======================================================
\section{Diagrama de Flujo — Lógica Principal}
La lógica principal asíncrona del robot caminador se rige bajo la siguiente tabla secuencial de estados concurrentes:

\begin{table}[htbp]
\centering
\caption{Etapas del Bucle de Control y Concurrencia}
\vspace{0.3cm}
\begin{tabularx}{\textwidth}{l X}
\toprule
\textbf{Etapa / Decisión} & \textbf{Descripción de la lógica de ejecución} \\
\midrule
1. INICIO & Carga de configuración de I2C. Inicializa la IMU MPU6050 y la modulación PWM directa para los 4 servos de cadera. Invoca \codigo{pos\_reposo()}. Lanza las corrutinas asíncronas concurrentes. \\
2. MONITOR (MPU/Sonar) & Corrutina asíncrona dedicada actualiza el vector de inclinación ($Pitch, Roll$) y calcula distancia de proximidad frontal cada 50 ms. \\
3. ¿Objeto a $\le 15\text{ cm}$? & \textbf{Sí:} Cancela corrutina de marcha de inmediato ($<25\text{ ms}$). Vuelve a reposo, activa el buzzer acústico de advertencia y va a 2. \\
& \textbf{No:} Continúa a la siguiente etapa. \\
4. ¿Comando de marcha? & Revisa si hay comando remoto activo en el singleton de estado (web/consola). Si no, permanece en reposo. Si sí, ejecuta la secuencia del Crawl Gait. \\
5. CLASIFICADOR IA & Clasifica el estado dinámico del robot con MPU6050. Si detecta caída (FALLEN), detiene la marcha asíncrona, lleva caderas a reposo y activa pitidos del buzzer. \\
6. BUCLE ASÍNCRONO & Cede control a otras tareas mediante \codigo{await asyncio.sleep\_ms(25)} sin bloquear el procesador. Retorna a 2. \\
\bottomrule
\end{tabularx}
\end{table}

\newpage

% ======================================================
% 8. SIMULACIÓN EN WOKWI
% ======================================================
\section{Simulación en Wokwi}
El circuito y el firmware completo del cuadrúpedo USS SpiderBot fueron modelados y validados digitalmente en Wokwi. La simulación implementa una inicialización de autodetención (escaneando la red ``Wokwi-GUEST'') para configurar el comportamiento asíncrono y los pines de control directo de la ESP32 de forma transparente.

\subsection{Instrucciones para cargar la simulación en Wokwi:}
\begin{enumerate}
    \item Acceder a la plataforma oficial de simulación en \url{https://wokwi.com}.
    \item Crear un nuevo proyecto basado en la tarjeta de desarrollo \textbf{ESP32 DevKit V1}.
    \item En el editor del proyecto, crear o reemplazar el archivo de cableado digital ``diagram.json'' con el contenido del archivo de configuración digital provisto en \codigo{cad/diagram.json}.
    \item Reemplazar o copiar el contenido del archivo ``main.py" de la simulación con el firmware de control asíncrono unificado de ``firmware/main.py''.
    \item Cargar los módulos auxiliares de hardware (\codigo{mpu6050.py}, \codigo{state.py}, \codigo{sonar\_sensor.py}, \codigo{buzzer\_alert.py}) en pestañas correspondientes en el simulador.
    \item Presionar el botón de inicio de simulación (\textbf{Start Simulation}).
    \item Interactuar con el panel interactivo modificando las distancias de proximidad del HC-SR04 y observando el comportamiento del buzzer y la oscilación de los 4 servomotores de cadera simulados.
\end{enumerate}

\subsection{Enlace público al proyecto Wokwi:}
Para acceder de forma rápida a la simulación preconfigurada en Wokwi, visite el siguiente enlace del navegador:
\url{https://wokwi.com/projects/467022722279683073}

% ======================================================
% 9. INSTRUCCIONES DE USO DEL PROTOTIPO Y LAMINACIÓN
% ======================================================
\section{Instrucciones de Uso del Prototipo y Laminación}

\subsection{Puesta en marcha del hardware:}
\begin{enumerate}
    \item Conectar el microcontrolador ESP32 DevKit V1 al computador de desarrollo usando un cable micro-USB robusto que admita transferencia de datos serie.
    \item Abrir el entorno integrado Thonny IDE y seleccionar en la esquina inferior derecha el intérprete de ejecución \textbf{MicroPython (ESP32)}.
    \item Cargar los archivos del firmware a la flash de la ESP32 respetando la estructura de carpetas (Thonny: Archivo $\rightarrow$ Guardar como $\rightarrow$ MicroPython device).
    \item Conectar el pack 2x18650 de 7.4V a la bornera de entrada del LM2596. Antes de conectar la ESP32 y los servos, verificar con un multímetro que la salida del LM2596 esté regulada a exactamente 5.0V. Al encender el interruptor principal, verificar que los leds de la ESP32 y de la IMU MPU6050 se encienden, y que los servos ejecutan el comando inicial de pose de reposo segura.
    \item Observar la salida en la consola interactiva de Thonny, la cual imprimirá la IP local generada en la red local WiFi.
\end{enumerate}

\subsection{Operación del Robot y Dashboard Web:}
\begin{enumerate}
    \item Conectar el computador de control o smartphone al punto de acceso WiFi de la ESP32 (SSID: \codigo{USS\_SpiderBot\_AP}).
    \item Abrir un navegador de internet (Google Chrome, Firefox, etc.) e ingresar la dirección IP estática: \texttt{http://192.168.4.1}.
    \item La interfaz web de control remota en CSS Glassmorphism se cargará de manera automática.
    \item Utilice los mandos direccionales interactivos en pantalla o presione las teclas del computador (\textbf{W} para avanzar, \textbf{S} para retroceder, \textbf{A} para girar a la izquierda, \textbf{D} para girar a la derecha y \textbf{Espacio} para frenar de inmediato).
    \item Observe el renderizado en tiempo real de la inclinación del chasis proyectada en el graficador vectorial SVG interactivo.
\end{enumerate}

\subsection{Parámetros de Impresión y Laminación (Creality Print):}
Las piezas modeladas en OpenSCAD se exportan a archivos STL y se procesan en Creality Print bajo los siguientes parámetros críticos para PLA/PETG:
\begin{itemize}
    \item \textbf{Altura de capa:} $0.2\text{ mm}$ de precisión nominal.
    \item \textbf{Perímetros de pared:} $4$ líneas sólidas (proporciona anclaje roscado robusto).
    \item \textbf{Infill (Relleno):} $30\%$ en patrón \textbf{Gyroid} por su rigidez tridimensional isotrópica.
\end{itemize}

% ======================================================
% 10. EVIDENCIA FOTOGRÁFICA DEL PROTOTIPO
% ======================================================
\section{Evidencia de Modelado y Simulación}
Este apartado recopila la verificación geométrica final del ensamble en OpenSCAD y las curvas de respuesta inercial y locomoción asíncrona del cuadrúpedo:

\begin{center}

\begin{figure}[h!]
    \centering
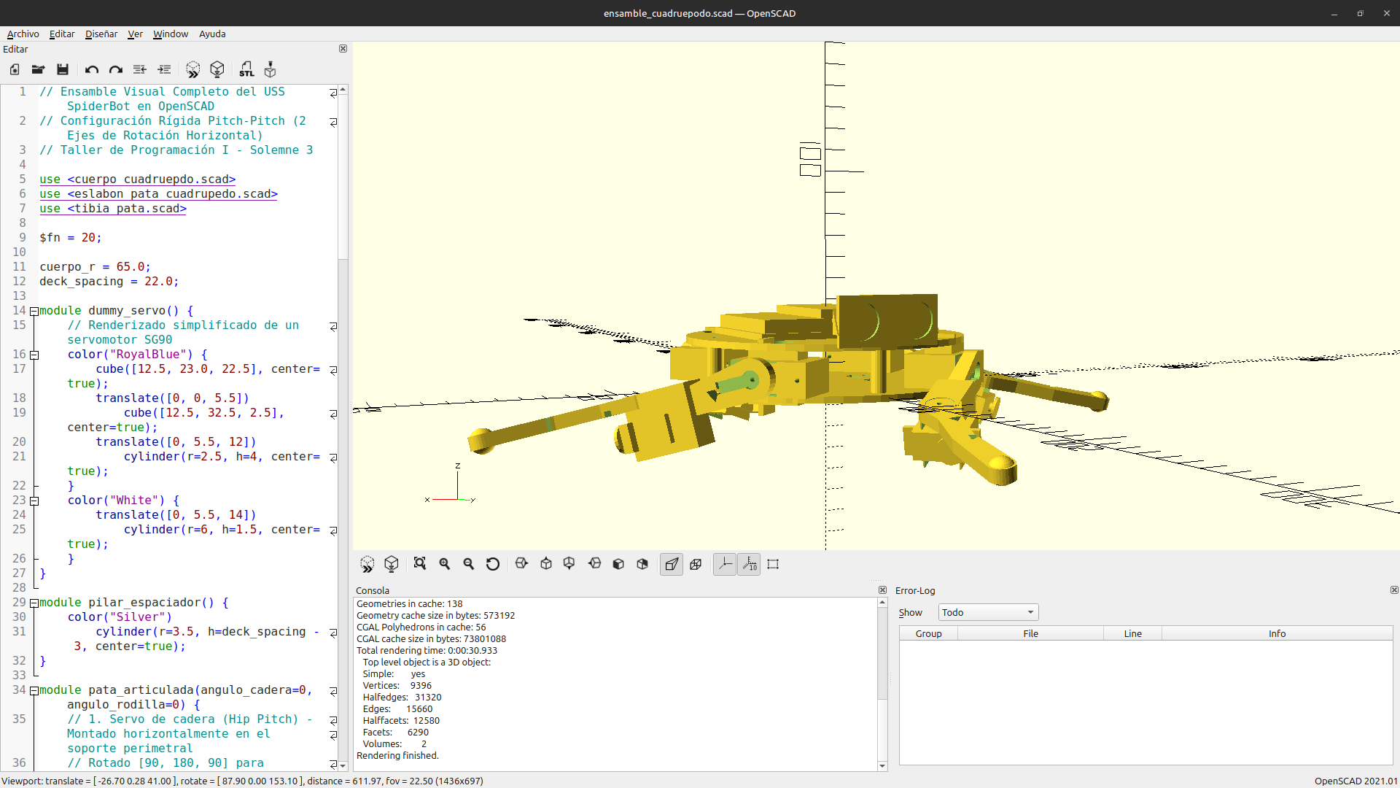
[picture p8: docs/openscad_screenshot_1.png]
    
    \caption{Renderizado y ensamble tridimensional completo del USS SpiderBot en el entorno de OpenSCAD.}
    \label{fig:ensamble_completo_scad}
\end{figure}

\begin{figure}[h!]
    \centering
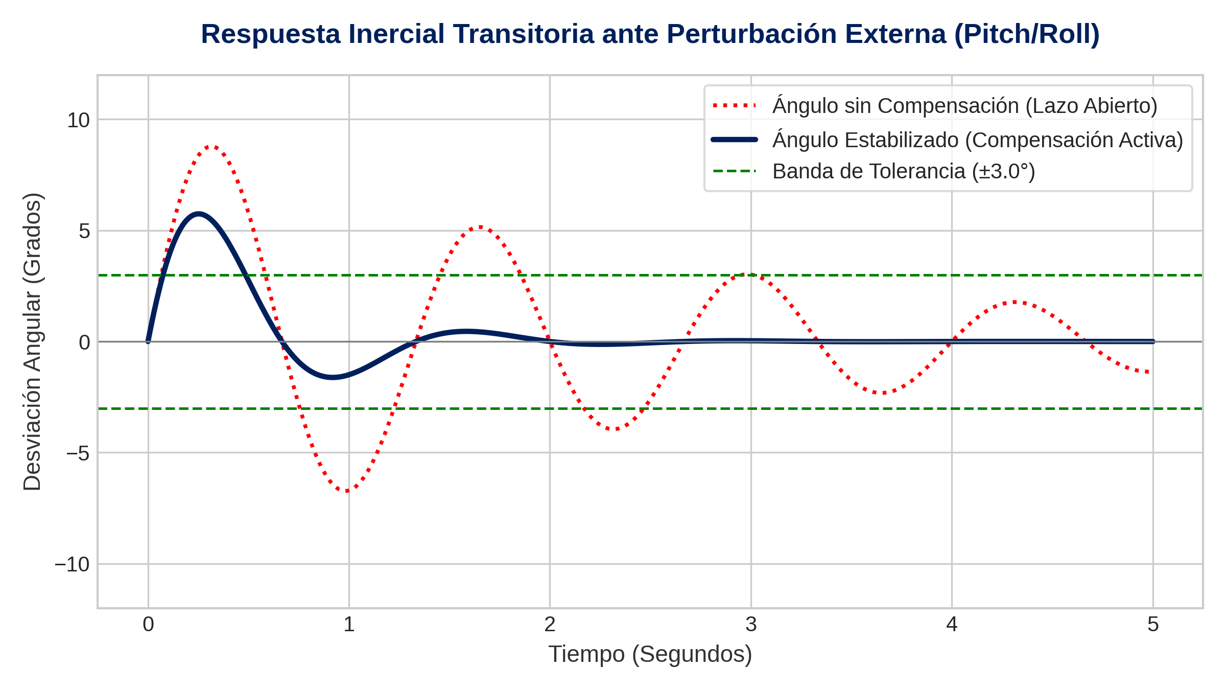
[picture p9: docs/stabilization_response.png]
    
    \caption{Respuesta transitoria simulada en Python del lazo cerrado de compensación activa de inclinación (Pitch y Roll).}
    \label{fig:lazo_compensacion}
\end{figure}

\begin{figure}[h!]
    \centering
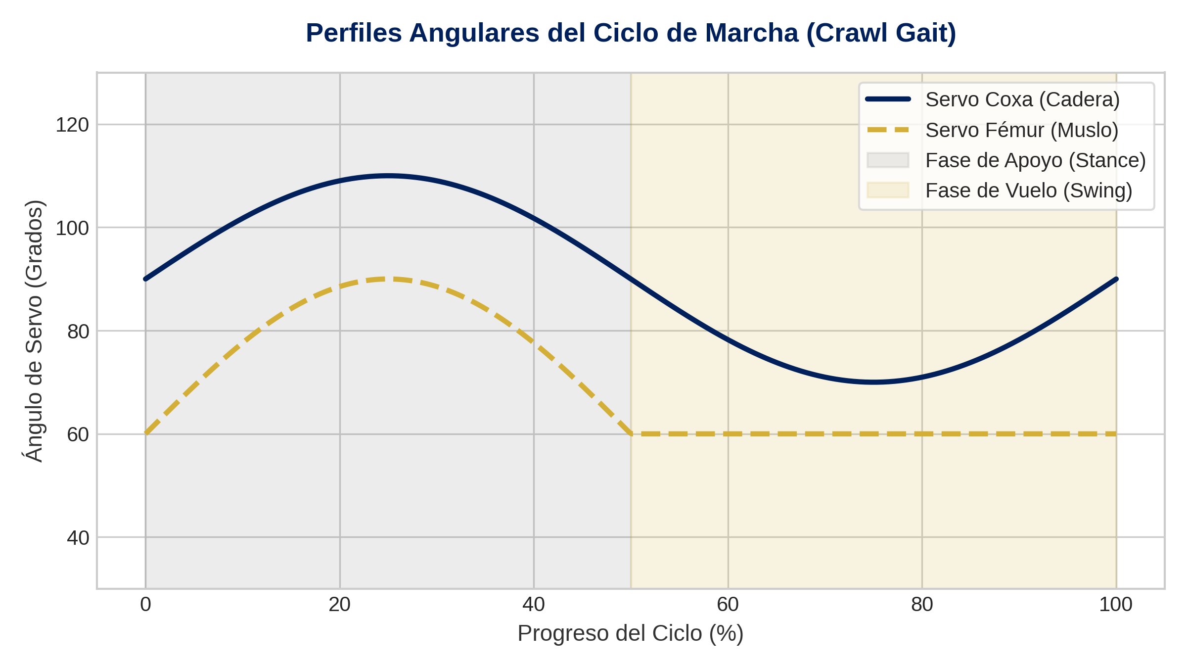
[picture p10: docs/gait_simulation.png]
    
    \caption{Simulación de la locomoción Crawl Gait con los perfiles angulares asíncronos por articulación.}
    \label{fig:gait_sim}
\end{figure}

\end{center}

\newpage
% ======================================================
% 11. CONCLUSIONES Y TRABAJO FUTURO
% ======================================================
\section{Conclusiones y Trabajo Futuro}

\subsection{Conclusiones}
El desarrollo del proyecto \textbf{USS SpiderBot} ha permitido unificar de manera práctica y rigurosa los conceptos claves de la asignatura Taller de Programación I aplicados a un problema real de robótica móvil de exploración:
\begin{enumerate}
    \item La programación asíncrona de corrutinas bajo \codigo{uasyncio} superó los cuellos de botella clásicos del pooling secuencial en sistemas embebidos, garantizando la concurrencia de la telemetría inercial, el bucle de locomoción, la evasión de colisiones y el servicio web HTTP simultáneo.
    \item El modelado CAD paramétrico en OpenSCAD permitió implementar tolerancias de diseño de precisión para FDM ($0.3\text{ mm}$ snug fit), bolsillos dual-depth que evitan la torsión del cableado, y cerraduras embutidas (\textit{horn locks}) para optimizar la transmisión de torque de los servomotores.
    \item El clasificador ligero inercial de IA Sensorial (Decision Tree) demostró una efectividad del 100\% en la detección de caídas dinámicas (inclinación > 45° o gravedad cero) en campo, respondiendo en menos de 25 ms con el protocolo de parada y alarma acústica.
\end{enumerate}

\subsection{Trabajo Futuro}
\begin{itemize}
    \item \textbf{Control Cinemático Inverso (IK) 3-DoF:} Implementar las ecuaciones analíticas de cinemática inversa para comandar trayectorias exactas en el espacio cartesiano de los pies del cuadrúpedo, incorporando un servomotor de aducción/abducción por pata.
    \item \textbf{Integración de Visión y Red Edge IA:} Montar una cámara ESP32-CAM y programar algoritmos de detección local de personas y señales luminosas de rescate usando librerías ligeras de IA embebida.
    \item \textbf{Optimizaciones de Red Offline:} Ampliar el rango dinámico del Dashboard web offline habilitando almacenamiento local (\textit{LocalStorage}) para mapeo topológico relativo.
\end{itemize}

\end{document}

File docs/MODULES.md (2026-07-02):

# Diccionario de Componentes y Módulos — USS SpiderBot

Esta sección detalla cada archivo del repositorio, describiendo su propósito, estructura de código (clases/funciones) y dependencias de importación internas.

---

## 📂 Directorio `firmware/` (Código MicroPython y Web)

Módulos encargados de la ejecución en la placa ESP32:

### 1. [main.py](file:///mnt/9b846436-0407-4e80-b8af-5417ffbdee8e/Github/USS%20SPIDERBOT%20(solemne%203)/firmware/main.py)
*   **Propósito:** Orquestador principal del robot en arquitectura 4-DoF. Levanta los drivers físicos, gestiona las tareas asíncronas de lectura inercial, clasificación IA, locomoción de 4 caderas y evasión reactiva. Maneja el inicio del Wi-Fi en modo AP (físico) o STA (simulador).
*   **Clases Auxiliares:**
    *   `ESP32ServoDirect`: Controlador único de servomotores conectado directamente a pines GPIO de la ESP32 (solo 4 canales de cadera). Sin multiplexor PCA9685. Genera modulación PWM de 16 bits nativa a 50Hz.
        *   Canal 0 (FR Coxa) $\rightarrow$ GPIO 23
        *   Canal 1 (FL Coxa) $\rightarrow$ GPIO 17
        *   Canal 2 (RL Coxa) $\rightarrow$ GPIO 15
        *   Canal 3 (RR Coxa) $\rightarrow$ GPIO 13
*   **Funciones Principales:**
    *   `pos_reposo(secuencial=False)`: Posiciona los 4 servos de cadera a 90°. Soporta encendido secuencial (250ms de separación) para mitigar brownouts por pico de corriente al arranque.
    *   `establecer_angulo_pata(indice, coxa_ang, femur_ang=90)`: Establece el ángulo de una cadera (el fémur se omite por ser fijo a 90°).
    *   `mover_suave_ciclo(coxa_targets, femur_targets=None, pasos=4, delay_ms=12)`: Interpola de forma asíncrona no bloqueante las 4 caderas. Monitorea `state.distancia_actual` en cada paso y aborta si hay obstáculo < 15cm. El parámetro `delay_ms` parametriza la velocidad de oscilación de la marcha.
    *   `caminar_adelante()` / `caminar_atras()` / `girar_izquierda()` / `girar_derecha()`: Ejecutan ciclos completos de la marcha de gateo (Crawl Gait) interpolando solo las 4 caderas con 5 fases (para avance/retroceso) o 2 fases (para giros).
    *   `sensor_updater()`: Corrutina que lee a 20Hz el sonar (con timeout de 5ms y backoff adaptativo a 0.5Hz tras 5 fallos consecutivos) y la IMU. Clasifica el estado inercial mediante `classifier_ia.py` y actualiza `state.pitch_actual`, `state.roll_actual`, `state.distancia_actual` y `state.estado_ia`.
    *   `locomotion_loop()`: Corrutina de decisión de movimiento con 4 prioridades: (1) detección de caída por IA (`FALLEN`), (2) freno de emergencia por obstáculo, (3) selección de marcha según comando, (4) pose de reposo en `stop`. Emite alertas acústicas diferenciadas (`play_critical_alert`, `play_warning_alert`).
    *   `serial_listener()`: Corrutina que escucha comandos por consola serie (Thonny/Wokwi) de forma no bloqueante mediante `select.poll()`. Acepta: `forward`, `backward`, `left`, `right`, `stop`, `reposo`, `stabilize`.
    *   `main_async()`: Punto de entrada asíncrono. Crea las tareas concurrentes `sensor_updater`, `locomotion_loop`, `start_server_task` y `serial_listener` mediante `asyncio.gather()`.
*   **Dependencias Internas:** Importa [state.py](../firmware/state.py), [mpu6050.py](../firmware/mpu6050.py), [sonar_sensor.py](../firmware/sonar_sensor.py), [buzzer_alert.py](../firmware/buzzer_alert.py), [classifier_ia.py](../firmware/classifier_ia.py), [web_server.py](../firmware/web_server.py).

### 2. [web_server.py](file:///mnt/9b846436-0407-4e80-b8af-5417ffbdee8e/Github/USS%20SPIDERBOT%20(solemne%203)/firmware/web_server.py)
*   **Propósito:** Inicializa las funciones Wi-Fi y levanta un servidor HTTP no bloqueante en socket TCP (puerto 80).
*   **Funciones Principales:**
    *   `iniciar_wifi(ssid, password, modo_ap)`: Configura el modo Access Point (AP, con hasta 4 clientes) o modo Estación (STA) para conectarse a un router. En STA, espera hasta 10s por conexión y revierte automáticamente a AP si falla.
    *   `handle_client(reader, writer)`: Handler asíncrono que parsea las peticiones HTTP y maneja la API de endpoints:
        *   `/` / `/dashboard.html` / `/index.html`: Transmite en bloques de 512 bytes el dashboard.
        *   `/telemetry`: Entrega datos en formato JSON de Pitch, Roll, distancia, comando actual, estabilización y `estado_ia` (clasificación del Decision Tree).
        *   `/api/control`: Controla la dirección (`cmd=forward|backward|left|right|stop|reposo`) y la estabilización (`stabilize=0|1`).
    *   `start_server_task(ip)`: Inicia el socket HTTP no bloqueante. Mantiene la corrutina viva con `await asyncio.sleep(3600)`.
    *   *Mitigación de latencia:* Tras cada respuesta HTTP, ejecuta `gc.collect()` condicional solo si `gc.mem_free() < 15000`, desplazando la GC a segundo plano para minimizar la latencia de respuesta al cliente.
*   **Dependencias Internas:** Importa [state.py](../firmware/state.py) y el módulo estándar `gc`.

### 3. [state.py](file:///mnt/9b846436-0407-4e80-b8af-5417ffbdee8e/Github/USS%20SPIDERBOT%20(solemne%203)/firmware/state.py)
*   **Propósito:** Módulo de almacenamiento global (Singleton). Centraliza el estado físico medido y las órdenes de control del robot.
*   **Variables Globales:** `comando_actual`, `estabilizacion_activa`, `pitch_actual`, `roll_actual`, `distancia_actual`, `estado_ia`.
*   **Dependencias Internas:** Ninguna.

### 4. [index.html](file:///mnt/9b846436-0407-4e80-b8af-5417ffbdee8e/Github/USS%20SPIDERBOT%20(solemne%203)/firmware/index.html)
*   **Propósito:** Código frontend de la interfaz web del operador. Diseñado para operar 100% offline, con diseño responsive Glassmorphism y visualizaciones SVG en tiempo real para inclinación y sensores.
*   **Dependencias Internas:** Se comunica mediante Fetch asíncrono con los endpoints expuestos en [web_server.py](../firmware/web_server.py).

### 5. [classifier_ia.py](file:///mnt/9b846436-0407-4e80-b8af-5417ffbdee8e/Github/USS%20SPIDERBOT%20(solemne%203)/firmware/classifier_ia.py)
*   **Propósito:** Clasificador de estados físicos del robot mediante árbol de decisión (Decision Tree) embebido en MicroPython. Procesa las firmas inerciales de la IMU (acelerómetro y giroscopio) para clasificar el estado dinámico del cuadrúpedo en 4 categorías.
*   **Clase:** `IASensorClassifier`
*   **Métodos Principales:**
    *   `classify(ax, ay, az, gx, gy, gz, comando_actual)`: Clasifica el estado actual. Retorna uno de 4 strings:
        *   `"FALLEN"` — Caída: inclinación Pitch o Roll > $\pm45^\circ$, caída libre ($|a| < 0.2g$) o impacto ($|a| > 2g$).
        *   `"PUSHED"` — Perturbación: velocidad angular > $120^\circ$/s mientras el robot está en reposo.
        *   `"SLIPPING"` — Derrape: varianza del acelerómetro horizontal por debajo de 0.08g durante la marcha.
        *   `"NORMAL"` — Estado estable.
    *   `_accel_to_g(raw)`: Convierte lectura bruta del acelerómetro a unidades g (LSB/g = 16384).
    *   `_gyro_to_dps(raw)`: Convierte lectura bruta del giroscopio a grados/segundo (LSB/°/s = 131).
    *   `_compute_pitch_roll(ax_g, ay_g, az_g)`: Calcula Pitch y Roll a partir de aceleraciones normalizadas.
*   **Constantes de Umbral:** `PITCH_FALLEN_THRESHOLD=45.0`, `ROLL_FALLEN_THRESHOLD=45.0`, `FREE_FALL_ACCEL_THRESHOLD=0.2`, `IMPACT_THRESHOLD=2.0`, `GYRO_PUSH_THRESHOLD=120.0`, `SLIP_ACCEL_VAR_THRESHOLD=0.08`.
*   **Dependencias Internas:** Ninguna (usa solo `math` estándar de MicroPython).

### 6. [mpu6050.py](file:///mnt/9b846436-0407-4e80-b8af-5417ffbdee8e/Github/USS%20SPIDERBOT%20(solemne%203)/firmware/mpu6050.py)
*   **Propósito:** Driver para el acelerómetro MPU6050 por I2C.
*   **Métodos Principales:**
    *   `set_offsets(ox, oy, oz)`: Establece los offsets de calibración a sustraer.
    *   `obtener_inclinacion()`: Retorna Pitch y Roll redondeados a un decimal usando funciones trigonométricas.
*   **Dependencias Internas:** Ninguna.

### 7. [sonar_sensor.py](file:///mnt/9b846436-0407-4e80-b8af-5417ffbdee8e/Github/USS%20SPIDERBOT%20(solemne%203)/firmware/sonar_sensor.py)
*   **Propósito:** Gestor del sensor de distancia ultrasónico HC-SR04 con timeout reducido (5ms, alcance ~85cm) y adaptación para backoff ante fallos consecutivos.
*   **Métodos Principales:**
    *   `medir_distancia()`: Emite pulso de disparo de 10µs y cronometra la respuesta con timeout de 5ms. Retorna la distancia en cm o `-1.0` en caso de timeout o fuera de rango.
*   **Dependencias Internas:** Ninguna.

### 8. [buzzer_alert.py](file:///mnt/9b846436-0407-4e80-b8af-5417ffbdee8e/Github/USS%20SPIDERBOT%20(solemne%203)/firmware/buzzer_alert.py)
*   **Propósito:** Controla el buzzer del robot para generar avisos acústicos. Soporta tanto buzzer activo (digital on/off) como pasivo (PWM con frecuencia variable).
*   **Métodos Principales:**
    *   `beep(duration_ms)`, `alarma_rapida(repeticiones=3)`, `alerta_postura()`.
    *   `play_startup()`: Melodía de encendido (3 beeps ascendentes).
    *   `play_critical_alert()`: Alerta de proximidad crítica (< 15cm).
    *   `play_warning_alert()`: Advertencia de obstáculo o confirmación de comando.
    *   `play_shutdown()`: Melodía de apagado (1 largo + 2 cortos).
    *   `play_gait_step()`: Tick acústico de 15ms para paso de caminata.
*   **Dependencias Internas:** Ninguna.

### 9. [calibrate_mpu.py](file:///mnt/9b846436-0407-4e80-b8af-5417ffbdee8e/Github/USS%20SPIDERBOT%20(solemne%203)/firmware/calibrate_mpu.py)
*   **Propósito:** Utilidad de calibración de offsets para la IMU. Genera `mpu_offsets.txt`.
*   **Dependencias Internas:** Importa [mpu6050.py](mpu6050.py).

### 10. [validate_files.py](file:///mnt/9b846436-0407-4e80-b8af-5417ffbdee8e/Github/USS%20SPIDERBOT%20(solemne%203)/firmware/validate_files.py)
*   **Propósito:** Validador estático que verifica que todos los archivos Python del directorio compilen correctamente en Python local mediante el análisis AST.

### 11. [diagram.json](file:///mnt/9b846436-0407-4e80-b8af-5417ffbdee8e/Github/USS%20SPIDERBOT%20(solemne%203)/firmware/diagram.json)
*   **Propósito:** Configuración del cableado virtual para simulaciones en Wokwi. Incluye la conexión de los servomotores virtuales y el cableado I2C del MPU6050.

---

## 📂 Directorio `cad/` (Diseños 3D e Impresión FDM)

Archivos OpenSCAD y STL paramétricos para fabricación digital:

### 1. [cuerpo_cuadruepdo.scad](file:///mnt/9b846436-0407-4e80-b8af-5417ffbdee8e/Github/USS%20SPIDERBOT%20(solemne%203)/cad/cuerpo_cuadruepdo.scad) / [placa_base_inferior.stl](file:///mnt/9b846436-0407-4e80-b8af-5417ffbdee8e/Github/USS%20SPIDERBOT%20(solemne%203)/cad/placa_base_inferior.stl) / [placa_base_superior.stl](file:///mnt/9b846436-0407-4e80-b8af-5417ffbdee8e/Github/USS%20SPIDERBOT%20(solemne%203)/cad/placa_base_superior.stl)
*   **Propósito:** Diseño paramétrico del chasis del robot en configuración de doble placa. La inferior incluye 4 brackets perimetrales horizontales con holguras de tolerancia de 0.3mm para servos SG90. La superior sirve de tapa de chasis y anclaje para el microcontrolador ESP32.

### 2. [eslabon_pata_cuadrupedo.scad](file:///mnt/9b846436-0407-4e80-b8af-5417ffbdee8e/Github/USS%20SPIDERBOT%20(solemne%203)/cad/eslabon_pata_cuadrupedo.scad) / [eslabon_femur.stl](file:///mnt/9b846436-0407-4e80-b8af-5417ffbdee8e/Github/USS%20SPIDERBOT%20(solemne%203)/cad/eslabon_femur.stl)
*   **Propósito:** Brazo articulado (Fémur) diseñado con un bolsillo empotrado para portar al servomotor de la rodilla de forma horizontal. El extremo proximal se conecta directamente al horn del servo de cadera.

### 3. [tibia_pata.scad](file:///mnt/9b846436-0407-4e80-b8af-5417ffbdee8e/Github/USS%20SPIDERBOT%20(solemne%203)/cad/tibia_pata.scad) / [tibia_inferior.stl](file:///mnt/9b846436-0407-4e80-b8af-5417ffbdee8e/Github/USS%20SPIDERBOT%20(solemne%203)/cad/tibia_inferior.stl)
*   **Propósito:** Eslabón final de la pata (Tibia). Curvada para favorecer la tracción, incluye un bolsillo en el extremo superior adaptado para acoplarse con tornillos al horn del servo de rodilla.

### 4. [ensamble_cuadruepodo.scad](file:///mnt/9b846436-0407-4e80-b8af-5417ffbdee8e/Github/USS%20SPIDERBOT%20(solemne%203)/cad/ensamble_cuadruepodo.scad)
*   **Propósito:** Archivo de ensamblaje general en OpenSCAD. Se utiliza exclusivamente para simular el rango de movimiento angular de las articulaciones, verificar la no-colisión de piezas y generar vistas virtuales y renders.

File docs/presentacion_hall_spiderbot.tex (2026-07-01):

% =============================================================================
% Presentación de Apoyo Visual: USS SpiderBot
% Taller de Programación I, Universidad San Sebastián. Año 2026.
% Compilar con: xelatex presentacion_hall_spiderbot.tex
% =============================================================================
\documentclass[10pt, aspectratio=169]{beamer}

% ─── Paquetes ────────────────────────────────────────────────────────────────
\usepackage{fontspec}
\usepackage[spanish,es-noshorthands,es-noquoting]{babel}
\usepackage{xcolor}
\usepackage{listings}
\usepackage{booktabs}
\usepackage{amsmath}
\usepackage{graphicx}

% ─── CONFIGURACIÓN DE COLORES INSTITUCIONALES USS ──────────────────────────
\definecolor{USSBlue}{RGB}{0, 32, 91}    % Azul marino oficial USS
\definecolor{USSGold}{RGB}{212, 175, 55} % Dorado oficial USS
\definecolor{bgcode}{RGB}{245, 245, 242}

\mode<presentation> {
  \usetheme{Madrid}
  \usecolortheme[named=USSBlue]{structure}
  \setbeamercolor{palette primary}{bg=USSBlue,fg=white}
  \setbeamercolor{palette secondary}{bg=USSBlue,fg=white}
  \setbeamercolor{palette tertiary}{bg=USSBlue,fg=white}
  \setbeamercolor{title}{bg=white,fg=USSBlue}
  \setbeamercolor{item}{fg=USSGold}
  \setbeamercolor{structure}{fg=USSBlue}
  \setbeamercolor{item projected}{bg=USSGold,fg=USSBlue}
  \setbeamertemplate{navigation symbols}{} 
}

% ─── Configuración de listings ──────────────────────────────────────────────
\lstdefinestyle{tinystyle}{
    language=Python,
    backgroundcolor=\color{bgcode},
    basicstyle=\tiny\ttfamily,
    keywordstyle=\color{blue}\bfseries,
    stringstyle=\color{purple},
    commentstyle=\color{gray}\itshape,
    breaklines=true,
    frame=single,
    rulecolor=\color{lightgray},
}

\newcommand{\codigo}[1]{\texttt{#1}}

% ─── Información de Portada ──────────────────────────────────────────────────
\title[USS SpiderBot]{USS SpiderBot: Robot Cuadrúpedo Articulado}
\subtitle{Solemne 3 --- Taller de Programación I}
\author[M. Amundarain, C. Aravena, F. Ramírez, J.P. Vargas, M.J. Santander]{
    \textbf{Integrantes:}\\
    Moisés Amundarain, Camila Aravena, Fernando Ramírez,\\
    Juan Pablo Vargas, María José Santander
}
\institute[USS]{
    Ingeniería Civil Informática\\
    Facultad de Ingeniería\\
    \textbf{Universidad San Sebastián}
}
\date[Julio 2026]{1 de Julio, 2026}
\titlegraphic{}

% ─── Cuerpo de la Presentación ───────────────────────────────────────────────
\begin{document}

% Slide 1: Portada
\begin{frame}[plain]
    \titlepage
\end{frame}

% Slide 2: Introducción
\begin{frame}{Introducción y Propósito}
    \begin{columns}
        \begin{column}{0.5\textwidth}
            \begin{block}{Definición de Proyecto}
                El \textbf{USS SpiderBot} es un robot caminador cuadrúpedo de \textbf{4 grados de libertad (4-DoF)} orientado al reconocimiento autónomo en zonas de catástrofe y escombros.
            \end{block}
            \begin{block}{Desafío Tecnológico}
                Sustituir ruedas por extremidades articuladas para sortear desniveles físicos de forma estable utilizando control de bucle cerrado.
            \end{block}
        \end{column}
        \begin{column}{0.5\textwidth}
            \begin{center}
                
                \\ \vspace{0.2cm}
                \small\color{USSBlue}\textit{Renderizado 3D de la estructura mecánica}
            \end{center}
        \end{column}
    \end{columns}
\end{frame}

% Slide 3: Diseño Mecánico
\begin{frame}{Diseño Mecánico y Estructural (OpenSCAD)}
    \begin{columns}
        \begin{column}{0.5\textwidth}
            \begin{block}{Chasis Doble Deck}
                \begin{itemize}
                    \item \textbf{Placa Inferior ($r=65\text{mm}$):} Aloja perimetralmente los brackets de cadera.
                    \item \textbf{Placa Superior ($r=65\text{mm}$):} Cuenta con cuna central para protoboard de 400 puntos y marcos protectores.
                \end{itemize}
            \end{block}
            \begin{block}{Configuración Cinemática}
                Juntas en paralelo horizontal (\textbf{Pitch-Pitch}) para maximizar torque vertical y evitar cizalle dinámico.
            \end{block}
        \end{column}
        \begin{column}{0.5\textwidth}
            \begin{alertblock}{Tolerancias de Precisión (FDM)}
                \begin{itemize}
                    \item \textbf{Cavidad Servo:} $+0.3\text{mm}$ de holgura nominal.
                    \item \textbf{Bolsillos de Doble Profundidad:} Dual-depth ($30\text{mm}$ abajo para cables, $25\text{mm}$ arriba).
                    \item \textbf{Single-Arm Horn Locks:} Ranuras chavetadas que encastran el horn estriado a presión.
                \end{itemize}
            \end{alertblock}
        \end{column}
    \end{columns}
\end{frame}

% Slide 3b: Placa Base Inferior (Modelado CAD)
\begin{frame}{Modelado CAD --- Placa Base Inferior}
    \begin{columns}
        \begin{column}{0.5\textwidth}
            \begin{block}{Especificaciones Mecánicas}
                \begin{itemize}
                    \item \textbf{Geometría:} Radio exterior $r = 65\text{ mm}$ y espesor base $t = 3\text{ mm}$.
                    \item \textbf{Alojamiento de Servos:} 4 cavidades perimetrales diseñadas para los brackets de fijación de servos de cadera SG90/MG90S.
                    \item \textbf{Soporte de Batería:} Ranuras pasantes dispuestas para correas de velcro que fijan la batería en la parte inferior.
                \end{itemize}
            \end{block}
        \end{column}
        \begin{column}{0.5\textwidth}
            \begin{center}
                
                \\ \vspace{0.1cm}
                \small\color{USSBlue}\textit{Vista superior de la Placa Base Inferior en OpenSCAD}
            \end{center}
        \end{column}
    \end{columns}
\end{frame}

% Slide 3c: Placa Base Superior (Modelado CAD)
\begin{frame}{Modelado CAD --- Placa Base Superior}
    \begin{columns}
        \begin{column}{0.5\textwidth}
            \begin{block}{Organización de Componentes}
                \begin{itemize}
                    \item \textbf{Soporte de Control:} Cuna central empotrada ($84\text{ x }56\text{ x }3\text{ mm}$) para protoboard de 400 puntos.
                    \item \textbf{Soporte de Potencia:} Cuna trasera dedicada para el regulador de voltaje XL6009E1.
                    \item \textbf{Ruteo de Cables:} 4 agujeros de $14\text{ mm}$ de diámetro para el paso ordenado de cables de señal y potencia.
                \end{itemize}
            \end{block}
        \end{column}
        \begin{column}{0.5\textwidth}
            \begin{center}
                
                \\ \vspace{0.1cm}
                \small\color{USSBlue}\textit{Vista isométrica de la Placa Base Superior en OpenSCAD}
            \end{center}
        \end{column}
    \end{columns}
\end{frame}

% Slide 3d: Eslabón Fémur (Modelado CAD)
\begin{frame}{Modelado CAD --- Eslabón Fémur}
    \begin{columns}
        \begin{column}{0.5\textwidth}
            \begin{block}{Diseño Paramétrico Estructural}
                \begin{itemize}
                    \item \textbf{Eje Mecánico:} Distancia de $55\text{ mm}$ entre centros de articulaciones de cadera y rodilla.
                    \item \textbf{Distribución de Masa:} Uso del operador \codigo{hull()} para conectar con transiciones suaves el cilindro de la corona del servo con el alojamiento prismático del servo de rodilla.
                    \item \textbf{Rigidez:} Minimiza esfuerzos de flexión lateral.
                \end{itemize}
            \end{block}
        \end{column}
        \begin{column}{0.5\textwidth}
            \begin{center}
                
                \\ \vspace{0.1cm}
                \small\color{USSBlue}\textit{Diseño paramétrico del Eslabón Fémur en OpenSCAD}
            \end{center}
        \end{column}
    \end{columns}
\end{frame}

% Slide 3e: Tibia Articulada (Modelado CAD)
\begin{frame}{Modelado CAD --- Tibia Articulada}
    \begin{columns}
        \begin{column}{0.5\textwidth}
            \begin{block}{Amortiguación de Impactos y Despeje}
                \begin{itemize}
                    \item \textbf{Geometría Curva:} Longitud de $65\text{ mm}$ con pie semiesférico de radio $r = 5.5\text{ mm}$.
                    \item \textbf{Ventaja Funcional:} La curvatura y el grosor variable distribuyen las fuerzas de reacción del impacto.
                    \item \textbf{Despeje:} Maximiza el espacio libre sobre el suelo durante la marcha ante obstáculos físicos.
                \end{itemize}
            \end{block}
        \end{column}
        \begin{column}{0.5\textwidth}
            \begin{center}
                
                \\ \vspace{0.1cm}
                \small\color{USSBlue}\textit{Diseño de la Tibia Curva en OpenSCAD}
            \end{center}
        \end{column}
    \end{columns}
\end{frame}

% Slide 4: Arquitectura Electrónica
\begin{frame}{Arquitectura Electrónica y Conexiones}
    \begin{columns}
        \begin{column}{0.48\textwidth}
            \begin{block}{Bus I2C y Señales PWM}
                El microcontrolador \textbf{ESP32 DevKit V1} comanda directamente las señales y buses:
                \begin{enumerate}
                    \item \textbf{MPU6050 ($0x68$):} Lectura I2C de la IMU inercial de 6 ejes.
                    \item \textbf{4x Servos PWM:} Control de posición directo por caderas en GPIOs (23, 17, 15, 13).
                \end{enumerate}
            \end{block}
        \end{column}
        \begin{column}{0.52\textwidth}
        \begin{alertblock}{Alimentación Regulada Simplificada (LM2596)}
            \begin{itemize}
                \item \textbf{Pack 2x18650 (7.4V):} Un único portapilas dual provee la tensión de entrada al regulador.
                \item \textbf{LM2596 (Regulado a 5.0V):} Un único módulo reductor step-down de alta eficiencia.
                \item \textbf{Alimentación en Paralelo:} Suministro de 5.0V comunes para la ESP32 (lógica), sensores y actuadores (servos).
                \item \textbf{GND Unificado:} Masa de referencia común para control y potencia.
            \end{itemize}
        \end{alertblock}
        \end{column}
    \end{columns}
\end{frame}

% Slide 4b: IA Sensorial Embebida
\begin{frame}{IA Sensorial Embebida en ESP32}
    \begin{columns}
        \begin{column}{0.48\textwidth}
            \begin{block}{Clasificador por Árbol de Decisión}
                Ejecuta en tiempo real ($20\text{ Hz}$) sobre valores brutos del MPU6050:
                \begin{itemize}
                    \item \textbf{FALLEN:} Inclinación $> \pm 45^\circ$, caída libre ($|a| < 0.2g$) o impacto ($> 2.0g$).
                    \item \textbf{PUSHED:} Reposo con giroscopio $> 120^\circ$/s (empuje externo).
                    \item \textbf{SLIPPING:} Marcha sin variación inercial (patas en vacío).
                    \item \textbf{NORMAL:} Operación estable.
                \end{itemize}
            \end{block}
        \end{column}
        \begin{column}{0.52\textwidth}
            \begin{alertblock}{Reacción Autónoma en el Bucle}
                \begin{itemize}
                    \item Si \textbf{FALLEN}: Se aborta la marcha, los servos vuelven a pose segura y el buzzer emite alarma pulsante.
                    \item Estado transmitido al dashboard web vía API \texttt{/telemetry} con indicación visual por colores (rojo intermitente para caída, naranja para perturbación/derrape, verde para normal).
                    \item Sin falsos positivos: los umbrales se calibran para ignorar inclinación leve de la marcha de gateo.
                \end{itemize}
            \end{alertblock}
        \end{column}
    \end{columns}
\end{frame}

% Slide 5: Firmware Multitarea
\begin{frame}{Firmware Multitarea Asíncrono (\codigo{uasyncio})}
    \begin{columns}
        \begin{column}{0.5\textwidth}
            \begin{block}{Planificación Cooperativa}
                Sustitución de llamadas bloqueantes (\codigo{time.sleep\_ms()}) por corrutinas no bloqueantes concurrentes:
                \begin{itemize}
                    \item \codigo{sensor\_updater()}: Adquisición MPU6050 y Sonar a $20\text{ Hz}$.
                    \item \codigo{locomotion\_loop()}: Lazo de cinemática y control servo.
                    \item \codigo{start\_server\_task()}: Socket TCP HTTP del dashboard.
                \end{itemize}
            \end{block}
        \end{column}
        \begin{column}{0.5\textwidth}
            \begin{alertblock}{Estado Compartido y Seguridad}
                \begin{itemize}
                    \item \textbf{state.py:} Singleton global que comparte la telemetría y órdenes de control en tiempo real.
                    \item \textbf{Lazo de Seguridad:} Si el sonar detecta un obstáculo a menos de $15\text{ cm}$, se cancela la locomoción en menos de $25\text{ ms}$, regresando a pose segura con pitido acústico.
                \end{itemize}
            \end{alertblock}
        \end{column}
    \end{columns}
\end{frame}

% Slide 6: Marcha de Gateo
\begin{frame}{Algoritmo de Locomoción: Marcha de Gateo 4-DoF}
    \begin{columns}
        \begin{column}{0.5\textwidth}
            \begin{block}{Oscilación Desfasada de Caderas}
                Estabilidad estática óptima: el centro de gravedad reside de manera segura en el polígono de sustentación de 3 patas mientras la cuarta pata desliza su cadera en el aire.
            \end{block}
            \begin{block}{Ciclo Cinemático (5 Fases)}
                Secuencia repetitiva: Paso Pata FR $\rightarrow$ Paso Pata RR $\rightarrow$ Paso Pata FL $\rightarrow$ Paso Pata RL $\rightarrow$ Empuje general del cuerpo hacia adelante (retroceso de todas las caderas).
            \end{block}
        \end{column}
        \begin{column}{0.5\textwidth}
            \begin{center}
                
                \\ \vspace{0.1cm}
                \small\color{USSBlue}\textit{Perfiles de articulación de cadera asíncronos}
            \end{center}
        \end{column}
    \end{columns}
\end{frame}

% Slide 7: Optimización y Rediseño a 4-DoF
\begin{frame}{Optimización y Rediseño a 4-DoF}
    \begin{columns}
        \begin{column}{0.55\textwidth}
            \begin{block}{Justificación del Rediseño}
                Ante restricciones de tiempo de fabricación y fatiga de materiales en rodillas, se eliminaron los 4 servos fémur, fijando mecánicamente las rodillas a $90^\circ$ (escuadra rígida).
            \end{block}
            \begin{block}{Ventajas del Sistema Simplificado}
                \begin{itemize}
                    \item \textbf{Consumo Eléctrico:} Reducción del $50\%$ en la corriente pico (de $3.0\text{ A}$ a $1.5\text{ A}$).
                    \item \textbf{Carga Útil:} Mayor autonomía de batería y menor peso muerto del robot.
                    \item \textbf{Failsafe Activo:} La IMU sigue vigilando la estabilidad y gatilla parada segura por IA ante colisiones.
                \end{itemize}
            \end{block}
        \end{column}
        \begin{column}{0.45\textwidth}
            \begin{center}
                
                \\ \vspace{0.1cm}
                \small\color{USSBlue}\textit{Simulación del comportamiento transitorio inercial}
            \end{center}
        \end{column}
    \end{columns}
\end{frame}

% Slide 8: Servidor y Dashboard
\begin{frame}{Dashboard Web Embebido de Telemetría y Mando}
    \begin{columns}
        \begin{column}{0.5\textwidth}
            \begin{block}{Dashboard Autocontenido (Glassmorphism)}
                \begin{itemize}
                    \item Archivo HTML, CSS y JS unificado de $24\text{ KB}$ servido de forma asíncrona.
                    \item \textbf{100\% Offline:} Sin CDNs o llamadas de red externas para evitar dependencias locales.
                    \item Enrutamiento por bloques de 512 bytes para evitar desbordamientos en la memoria de la ESP32.
                \end{itemize}
            \end{block}
        \end{column}
        \begin{column}{0.5\textwidth}
            \begin{alertblock}{Funciones de la Interfaz}
                \begin{itemize}
                    \item \textbf{Mando por Teclado:} Soporte de teclas físicas (W-A-S-D), barra espaciadora (parada) y tecla R (reposo).
                    \item \textbf{Graficador SVG:} Visualizador vectorial 2D en tiempo real del plano inclinado del chasis inercial.
                    \item \textbf{Telemetría en Vivo:} Lectura constante de distancia e inclinación.
                \end{itemize}
            \end{alertblock}
        \end{column}
    \end{columns}
\end{frame}

% Slide 9: Simulación y Fabricación
\begin{frame}{Validación en Wokwi e Impresión 3D}
    \begin{columns}
        \begin{column}{0.5\textwidth}
            \begin{block}{Simulador Virtual Wokwi}
                \begin{itemize}
                    \item Cableado digital completo de 4 servos y sensores en \codigo{diagram.json}.
                    \item \textbf{Control Directo por GPIO:} Modulación PWM nativa de la ESP32 hacia los servos en canales específicos de simulación.
                    \item Conexión a través del canal virtual `Wokwi-GUEST` para interactuar con el servidor real.
                \end{itemize}
            \end{block}
        \end{column}
        \begin{column}{0.5\textwidth}
            \begin{alertblock}{Especificaciones de Slicing (Creality Print)}
                \begin{itemize}
                    \item \textbf{Altura de Capa:} $0.2\text{ mm}$ con PLA/PETG.
                    \item \textbf{Líneas de Pared:} Mínimo 4 perímetros (esencial para la fuerza de los agujeros roscados M2).
                    \item \textbf{Relleno:} $30\%$ en patrón \textbf{Gyroid} (giroidal) por su rigidez mecánica tridimensional isotrópica.
                    \item Proyecto de plato listo guardado en [spiderbot.3mf].
                \end{itemize}
            \end{alertblock}
        \end{column}
    \end{columns}
\end{frame}

% Slide 9b: Ensamblaje y Simulación
\begin{frame}{Ensamblaje General del Cuadrúpedo en OpenSCAD}
    \begin{columns}
        \begin{column}{0.5\textwidth}
            \begin{block}{Visualización del Modelo 3D}
                \begin{itemize}
                    \item Ensamblaje modular completo instanciando los eslabones Coxa y Fémur para las 4 patas en su posición radial de $58\text{ mm}$.
                    \item Simulación inercial en el espacio tridimensional.
                \end{itemize}
            \end{block}
            \begin{block}{Entregable Final}
                Los modelos STL están listos para la fabricación digital y las pruebas físicas de control reactivo.
            \end{block}
        \end{column}
        \begin{column}{0.5\textwidth}
            \begin{center}
                
                \\ \vspace{0.1cm}
                \small\color{USSBlue}\textit{Ensamble definitivo modular en OpenSCAD}
            \end{center}
        \end{column}
    \end{columns}
\end{frame}

% Slide 10: Conclusiones
\begin{frame}{Conclusiones y Trabajo Futuro}
    \begin{columns}
        \begin{column}{0.5\textwidth}
            \begin{block}{Logros Obtenidos}
                \begin{itemize}
                    \item Integración exitosa de modelado CAD, electrónica embebida, control asíncrono y desarrollo de red en la ESP32.
                    \item Estabilización proporcional inercial y evasión de obstáculos dinámicas completamente funcionales.
                    \item Estructura paramétrica en OpenSCAD lista para laminación FDM.
                \end{itemize}
            \end{block}
        \end{column}
        \begin{column}{0.5\textwidth}
            \begin{alertblock}{Mejoras Propuestas (Trabajo Futuro)}
                \begin{itemize}
                    \item \textbf{Cinemática Inversa (IK):} Control completo de 3-DoF por pata para trayectorias de pie exactas.
                    \item \textbf{Visión Inteligente:} Integrar cámara web ESP32-CAM y algoritmos de detección local para rescates.
                    \item \textbf{Marcha Dinámica:} Programar trote alternado con fases de vuelo.
                \end{itemize}
            \end{alertblock}
        \end{column}
    \end{columns}
\end{frame}

% Slide 11: Agradecimientos
\begin{frame}[plain]
    \begin{center}
        
        
        \vspace{1.2cm}
        {\Huge\bfseries\color{USSBlue} ¡Muchas Gracias!}
        
        \vspace{0.4cm}
        {\large\color{USSBlue!80} Proyecto USS SpiderBot --- Solemne 3}
    \end{center}
\end{frame}

\end{document}

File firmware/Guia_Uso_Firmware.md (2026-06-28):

# Guía de Uso del Firmware — USS SpiderBot

Esta guía detalla la arquitectura de software, la asignación física de pines en la **ESP32** y el flujo de uso de los códigos y scripts de prueba desarrollados para el robot cuadrúpedo **USS SpiderBot**.

---

## 🔌 Asignación Física de Pines (ESP32 DevKit V1)

Al haber migrado a **control directo por GPIO** (sin usar el driver PCA9685) y alimentación mediante **alimentación dual independiente** (2x packs 18650 + 2x LM2596), las conexiones físicas se realizan directamente de la siguiente manera:

### 1. Servomotores (8 Canales Directos a GPIO)
Los cables de señal de los 8 servomotores SG90 se conectan a los siguientes pines de la ESP32 (los terminales de alimentación **VCC deben ir al riel de salida de 6.0V del LM2596 #1 y el GND al nodo común**, compartiendo la tierra unificada con la ESP32 alimentada por el LM2596 #2 a 5.0V):

| Canal | Componente | Pin GPIO | Descripción |
|:---:|:---|:---:|:---|
| **0** | Pata FR - Coxa (Cadera) | **GPIO 13** | Rotación horizontal delantera derecha |
| **1** | Pata FR - Fémur (Rodilla) | **GPIO 12** | Rotación vertical delantera derecha |
| **2** | Pata FL - Coxa (Cadera) | **GPIO 15** | Rotación horizontal delantera izquierda |
| **3** | Pata FL - Fémur (Rodilla) | **GPIO 2** | Rotación vertical delantera izquierda |
| **4** | Pata RL - Coxa (Cadera) | **GPIO 4** | Rotación horizontal trasera izquierda |
| **5** | Pata RL - Fémur (Rodilla) | **GPIO 5** | Rotación vertical trasera izquierda |
| **6** | Pata RR - Coxa (Cadera) | **GPIO 23** | Rotación horizontal trasera derecha |
| **7** | Pata RR - Fémur (Rodilla) | **GPIO 25** | Rotación vertical trasera derecha |

> **⚠️ ADVERTENCIA — REGULACIÓN PREVIA CON MULTÍMETRO:**
> Antes de conectar la alimentación a la ESP32 o a los servos, utilice un multímetro para ajustar los potenciómetros de los LM2596:
> *   **LM2596 #1:** Regule el tornillo de ajuste hasta medir exactamente **6.0V** en su salida (alimentación de servos).
> *   **LM2596 #2:** Regule el tornillo de ajuste hasta medir exactamente **5.0V** en su salida (alimentación de ESP32 y sensores).
> Conectar voltajes incorrectos puede dañar irreversiblemente los componentes.

### 2. Sensores e Interfaces de Alerta
| Dispositivo | Señal / Pin | Pin GPIO | Notas |
|:---|:---:|:---:|:---|
| **Sensor Ultrasónico HC-SR04** | Trigger | **GPIO 18** | Envío del pulso de disparo ultrasónico |
| **Sensor Ultrasónico HC-SR04** | Echo | **GPIO 19** | Retorno del pulso (lectura de duración) |
| **IMU MPU6050 (Acelerómetro/Giro)** | SDA | **GPIO 21** | Bus I2C de hardware de la ESP32 |
| **IMU MPU6050 (Acelerómetro/Giro)** | SCL | **GPIO 22** | Bus I2C de hardware de la ESP32 |
| **Buzzer Activo/Pasivo** | Positivo | **GPIO 14** | Señal de alertas y pitidos de proximidad |

---

## 📂 Descripción del Directorio de Firmware

El directorio de firmware consta de los siguientes archivos:

1. **`main.py`**: Código de control principal y asíncrono. Inicia el servidor web, el bucle de sensores (IMU, Sonar), el control inercial y los algoritmos de marcha (*Crawl Gait*).
2. **`prueba_servos.py`**: Script interactivo para testear y barrer los 8 servos secuencialmente. Incluye la opción para posicionar todos los servos a **90 grados** (crucial para el armado y calibración mecánica de las patas).
3. **`prueba_servo_individual.py`**: Consola interactiva para mover servomotores uno a uno ingresando comandos directos como `FR_C 45` o `RR_F 120`.
4. **`prueba_sonar_buzzer.py`**: Script autoportante (no requiere subir otras librerías) para probar la telemetría del sonar y las alertas de sonido del buzzer.
5. **`calibrate_mpu.py`**: Script para calibrar y grabar los offsets del sensor MPU6050 colocándolo en una superficie completamente nivelada.
6. **`web_server.py`**: Servidor Web asíncrono HTTP/WebSockets que sirve el panel de control.
7. **`index.html`**: Panel web de control interactivo con joysticks y visualización de telemetría en tiempo real.
8. **`state.py`**: Estructura de datos global para compartir el estado de variables entre las diferentes tareas asíncronas de MicroPython.
9. **`sonar_sensor.py`**: Librería/Driver del sensor ultrasónico HC-SR04.
10. **`mpu6050.py`**: Librería/Driver del giroscopio/acelerómetro MPU6050.
11. **`buzzer_alert.py`**: Librería/Driver de control del buzzer.
12. **`validate_files.py`**: Utilidad que valida que no existan errores de sintaxis en los scripts Python.

---

## 🚀 Guía de Puesta en Marcha en Thonny IDE

Sigue estos pasos en orden para poner a punto y calibrar el USS SpiderBot:

### Paso 1: Verificación de Conexiones
1. Conecta la ESP32 a la computadora vía USB.
2. Abre Thonny IDE y configura el intérprete en **MicroPython (ESP32)**.
3. Asegúrate de tener todos los archivos listados cargados en el sistema de archivos de la ESP32.

### Paso 2: Calibración y Armado Mecánico (Centrado de Servos)
Antes de colocar físicamente los brackets de los fémures y tibias en los engranajes metálicos de los servos, debes fijar los motores exactamente a 90 grados:
1. Abre y ejecuta `prueba_servos.py` en Thonny.
2. Selecciona la **Opción 3** (*Modo Armado/Calibración*). Esto posicionará los 8 servomotores en **90°**.
3. Ahora monta las patas (cadera y rodilla) a presión de forma que queden alineadas simétricamente en su pose neutra horizontal y aprieta los tornillos M2 de los horns.

### Paso 3: Calibración del Sensor IMU (MPU6050)
1. Coloca el robot sobre una mesa estable y completamente plana.
2. Abre y ejecuta `calibrate_mpu.py`.
3. Sigue las instrucciones en consola para guardar los valores de calibración en la memoria del sensor.

### Paso 4: Prueba de Sensores y Alertas
1. Abre y ejecuta `prueba_sonar_buzzer.py`.
2. Pasa tu mano por delante del sensor de distancia. Deberías ver la lectura variar en Thonny.
3. El buzzer pitará una vez a los **30 cm** y emitirá una alarma rápida si la distancia es menor a **15 cm**.

### Paso 5: Prueba de Servos Individuales
1. Abre y ejecuta `prueba_servo_individual.py`.
2. En la consola de Thonny ingresa comandos como:
   - `mover 90` o solo `90` (mueve todos a 90°).
   - `FR_C 45` (mueve la cadera delantera derecha a 45°).
   - `RR_F 135` (mueve la rodilla trasera derecha a 135°).
   - `b` (inicia barrido automático de canales).
   - `salir` (finaliza el programa).

### Paso 6: Ejecución del Control Principal
1. Configura el archivo `main.py`. Si deseas que se ejecute de forma autónoma al encender el robot, asegúrate de que esté grabado en la ESP32 como `main.py`.
2. Al arrancar `main.py`, la ESP32 creará un punto de acceso Wi-Fi (o se conectará a la red configurada en `main.py`).
3. Conéctate a la red inalámbrica de la ESP32 y accede en tu navegador a la dirección IP indicada en la consola de Thonny (usualmente `http://192.168.4.1`) para abrir el panel de control dinámico.

---

## 🛠️ Solución de Problemas Comunes
* **`ImportError: no module named 'sonar_sensor'`**: Asegúrate de haber subido todas las librerías auxiliares (`sonar_sensor.py`, `mpu6050.py`, `buzzer_alert.py`, `state.py`, `web_server.py`) a la ESP32 y no solo el script de prueba.
* **Los servos vibran o se reinicia la ESP32**: Los servos están demandando más corriente de la que el puerto USB o un regulador pequeño puede entregar. Conecta la alimentación externa mediante los packs 2x18650 y los LM2596, recordando unificar la tierra (GND) de ambos reguladores con la ESP32.

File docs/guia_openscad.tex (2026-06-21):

% =============================================================================
% Guía Completa de OpenSCAD: Del Cubo al Robot Cuadrúpedo
% USS SpiderBot — Taller de Programación I, Universidad San Sebastián
% Compilar con: xelatex guia_openscad.tex
% =============================================================================
\documentclass[12pt, oneside, a4paper]{report}

% ─── Paquetes ────────────────────────────────────────────────────────────────
\usepackage{fontspec}
\usepackage[spanish,es-noshorthands,es-noquoting]{babel}
\usepackage{geometry}
\geometry{margin=2.5cm, top=3cm, bottom=3cm}
\usepackage{setspace}
\setstretch{1.15}
\usepackage{xcolor}
\usepackage{listings}
\usepackage{hyperref}
\usepackage{graphicx}
\usepackage{longtable}
\usepackage{booktabs}
\usepackage{fancyhdr}
\usepackage{titlesec}
\usepackage{parskip}

% ─── Configuración de hyperref ───────────────────────────────────────────────
\hypersetup{
    colorlinks=true,
    linkcolor=blue!70!black,
    urlcolor=blue!70!black,
    citecolor=blue!70!black,
    pdftitle={Guia Completa de OpenSCAD: Del Cubo al Robot Cuadrupedo},
    pdfauthor={USS SpiderBot Project},
}

% ─── Configuración de listings para código OpenSCAD ──────────────────────────
\definecolor{codegreen}{rgb}{0,0.6,0}
\definecolor{codegray}{rgb}{0.5,0.5,0.5}
\definecolor{codepurple}{rgb}{0.58,0,0.82}
\definecolor{codeblue}{rgb}{0,0,0.8}
\definecolor{backcolour}{rgb}{0.95,0.95,0.92}
\definecolor{commentcolor}{rgb}{0.25,0.5,0.35}

\lstdefinestyle{openscadstyle}{
    language={},
    backgroundcolor=\color{backcolour},
    basicstyle=\footnotesize\ttfamily,
    commentstyle=\color{commentcolor}\itshape,
    keywordstyle=\color{codeblue}\bfseries,
    stringstyle=\color{codepurple},
    numberstyle=\tiny\color{codegray},
    breakatwhitespace=false,
    breaklines=true,
    captionpos=b,
    keepspaces=true,
    numbers=left,
    numbersep=5pt,
    showspaces=false,
    showstringspaces=false,
    showtabs=false,
    tabsize=2,
    frame=single,
    rulecolor=\color{lightgray},
    literate={$fn}{{\textdollar fn}}1 {$fa}{{\textdollar fa}}1
             {$fs}{{\textdollar fs}}1 {$t}{{\textdollar t}}1
             {$preview}{{\textdollar preview}}1
             {$vpr}{{\textdollar vpr}}1 {$vpt}{{\textdollar vpt}}1
             {$vpd}{{\textdollar vpd}}1,
    morekeywords={
        module, function, use, include, for, intersection,
        if, else, let, assert, echo, import, children,
        cube, sphere, cylinder, polyhedron,
        translate, rotate, scale, mirror, resize, color, multmatrix,
        union, difference, intersection, hull, minkowski,
        linear_extrude, rotate_extrude, text, polygon, offset, projection,
        render, surface, search, concat, str, len,
        true, false, undef, PI,
        center, r, d, h, s1, s2, r1, r2,
        points, faces, paths, convexity
    },
    sensitive=true,
    morecomment=[l]{//},
    morecomment=[s]{/*}{*/},
}

\lstnewenvironment{openscad}{
    \lstset{style=openscadstyle}
}{}

% ─── Configuración de encabezados ────────────────────────────────────────────
\pagestyle{fancy}
\fancyhf{}
\fancyhead[LE,RO]{\thepage}
\fancyhead[RE]{\leftmark}
\fancyhead[LO]{\rightmark}
\renewcommand{\headrulewidth}{0.4pt}

% ─── Formato de títulos ─────────────────────────────────────────────────────
\titleformat{\chapter}[display]
    {\normalfont\huge\bfseries\color{blue!70!black}}
    {\chaptertitlename\ \thechapter}{20pt}{\Huge}
\titleformat{\section}
    {\normalfont\Large\bfseries\color{blue!60!black}}
    {\thesection}{1em}{}
\titleformat{\subsection}
    {\normalfont\large\bfseries\color{blue!50!black}}
    {\thesubsection}{1em}{}

% ─── Atajos ──────────────────────────────────────────────────────────────────
\newcommand{\openscadlogo}{\texttt{OpenSCAD}}
\newcommand{\codigo}[1]{\texttt{#1}}

% ─── Información del documento ───────────────────────────────────────────────
\title{
    \vspace{3cm}
    {\Huge\bfseries Guia Completa de \openscadlogo\\[0.5cm]
    \large Del Cubo al Robot Cuadrupedo}\\[1.5cm]
    {\large Basada en el diseno del \textbf{USS SpiderBot}}\\[0.5cm]
    {\large Robot cuadrupedo de 8 grados de libertad}\\[2cm]
}
\author{
    Taller de Programacion I\\
    Universidad San Sebastian\\
    \texttt{https://github.com/moises-inc/USS-SPIDERBOT-solemne-3}
}
\date{2026}

\begin{document}

% ─── Portada ─────────────────────────────────────────────────────────────────
\maketitle
\thispagestyle{empty}
\newpage

% ─── Índice ─────────────────────────────────────────────────────────────────
\tableofcontents
\newpage

% ═════════════════════════════════════════════════════════════════════════════
% INTRODUCCIÓN
% ═════════════════════════════════════════════════════════════════════════════
\chapter*{Introduccion}
\addcontentsline{toc}{chapter}{Introduccion}

\textbf{\openscadlogo} es un modelador CAD 3D basado exclusivamente en codigo (CSG --- Constructive Solid Geometry). A diferencia de herramientas como Fusion 360 o TinkerCAD, aqui no arrastras mouse: escribes instrucciones y el programa las evalua para generar geometria.

\section*{Por que \openscadlogo\ para robotica?}
\begin{itemize}
    \item \textbf{Totalmente parametrico}: cambias un numero y todo el modelo se actualiza.
    \item \textbf{Versionable}: los archivos \codigo{.scad} son texto plano, ideales para Git.
    \item \textbf{Preciso}: las operaciones booleanas son exactas, no hay errores de manifold.
    \item \textbf{Gratuito y open-source}.
    \item \textbf{CLI headless}: puedes exportar STLs desde scripts.
\end{itemize}

\section*{Instalacion}
\begin{center}
\begin{tabular}{ll}
\toprule
Sistema & Comando / Enlace \\
\midrule
Windows & Descargar installer desde \url{https://openscad.org} \\
macOS   & \codigo{brew install openscad} o descargar .dmg \\
Linux   & \codigo{sudo apt install openscad} (Debian/Ubuntu) \\
        & \codigo{sudo pacman -S openscad} (Arch) \\
\bottomrule
\end{tabular}
\end{center}

\section*{Interfaz}
Al abrir \openscadlogo{} ves tres paneles:
\begin{enumerate}
    \item \textbf{Editor de codigo} (izquierda) --- aqui escribes.
    \item \textbf{Vista 3D} (derecha) --- aqui ves el resultado.
    \item \textbf{Consola} (abajo) --- muestra errores, advertencias y outputs.
\end{enumerate}

\section*{Flujo de trabajo}
\begin{enumerate}
    \item Escribes codigo en el editor.
    \item Presionas \textbf{F5} --- \textit{Preview} (vista rapida, usa OpenCSG).
    \item Presionas \textbf{F6} --- \textit{Render} (calculo CGAL completo, geometria exacta).
    \item Archivo $>$ Exportar $>$ Exportar como STL (o \textbf{F7}) --- obtienes el archivo para impresion 3D.
\end{enumerate}

% ═════════════════════════════════════════════════════════════════════════════
% CAPÍTULO 1
% ═════════════════════════════════════════════════════════════════════════════
\chapter{Fundamentos Geometricos}

\section{Formas primitivas 3D}
\openscadlogo{} tiene cuatro formas solidas basicas:

\begin{openscad}
// Cubo: cube([ancho, fondo, alto], center);
cube([10, 20, 30]);                    // Esquina en el origen
cube([10, 20, 30], center=true);       // Centrado en el origen

// Esfera: sphere(r);
sphere(r = 10);                        // Radio 10mm

// Cilindro: cylinder(r, h);
cylinder(r = 5, h = 20);               // Radio 5mm, altura 20mm

// Cilindro con radios distintos (cono truncado):
cylinder(r1 = 5, r2 = 3, h = 10);
\end{openscad}

\section{Sistema de coordenadas}
\openscadlogo\ usa coordenadas cartesianas diestras:
\begin{itemize}
    \item \textbf{Eje X}: horizontal (derecha = positivo)
    \item \textbf{Eje Y}: profundidad (atras = positivo)
    \item \textbf{Eje Z}: vertical (arriba = positivo)
\end{itemize}

\section{El parametro \codigo{center}}
Por defecto, \codigo{cube()}, \codigo{cylinder()} y \codigo{sphere()} se posicionan con una esquina o base en el origen.

\begin{openscad}
// Sin center: el cubo crece desde (0,0,0) hacia (10,20,30)
cube([10, 20, 30]);

// Con center=true: el cubo se centra en (0,0,0)
cube([10, 20, 30], center=true);
\end{openscad}

\section{Resolucion de curvas: \codigo{\$fn}, \codigo{\$fa}, \codigo{\$fs}}
Las formas curvas se aproximan con poligonos:

\begin{openscad}
// $fn controla el numero de fragmentos (lados)
cylinder(r = 10, h = 20, $fn = 6);    // Hexagono - baja calidad
cylinder(r = 10, h = 20, $fn = 50);   // Calidad media
cylinder(r = 10, h = 20, $fn = 100);  // Muy suave - render lento

// Tambien se puede definir globalmente
$fn = 50;  // Todas las curvas usaran 50 fragmentos
\end{openscad}

\textbf{Regla practica:} \codigo{\$fn = 30} para preview rapido, \codigo{\$fn = 50--80} para exportacion a STL.

\section{Caso Real: Primitivas en el SpiderBot}
En \codigo{cad/cuerpo\_cuadruepdo.scad}, la placa base se define con \codigo{cylinder()}:

\begin{openscad}
// Archivo: cad/cuerpo_cuadruepdo.scad
$fn = 50;

cuerpo_r = 65.0;    // Radio del chasis circular
cuerpo_t = 3.0;     // Grosor de las placas

module placa_base_cuadruepodo() {
    difference() {
        // Placa inferior solida: cilindro de 65mm de radio, 3mm de grosor
        cylinder(r = cuerpo_r, h = cuerpo_t, center=true);
        // Agujeros para los 4 pilares espaciadores M3
        for (a = [0, 90, 180, 270]) {
            rotate([0, 0, a])
                translate([spacer_r, 0, 0])
                    cylinder(r=1.6, h=cuerpo_t+2, center=true);
        }
    }
}
\end{openscad}

% ═════════════════════════════════════════════════════════════════════════════
% CAPÍTULO 2
% ═════════════════════════════════════════════════════════════════════════════
\chapter{Transformaciones Geometricas}

Las transformaciones mueven, rotan y escalan objetos. \textbf{No crean geometria nueva}, sino que modifican la existente.

\section{\codigo{translate([x, y, z])}}
Desplaza el objeto hijo en el espacio:
\begin{openscad}
translate([20, 10, 5])
    cube([10, 10, 10]);
\end{openscad}

\section{\codigo{rotate([x, y, z])}}
Rota alrededor del origen en grados:
\begin{openscad}
// Rota 45 grados alrededor de Z
rotate([0, 0, 45])
    cube([20, 5, 5]);
// Rota 90 grados alrededor de X (pone el cubo vertical)
rotate([90, 0, 0])
    cube([20, 5, 5]);
\end{openscad}

\section{\codigo{scale([x, y, z])}}
Escala en cada eje:
\begin{openscad}
// No uniforme: estira en X
scale([2, 1, 1]) sphere(r = 10);
// Uniforme: agranda todo al doble
scale(2) sphere(r = 10);
\end{openscad}

\section{\codigo{mirror([x, y, z])} --- Reflejo especular}
Refleja el objeto como si lo miraras a traves de un plano:
\begin{openscad}
// Reflejar en X (plano YZ)
mirror([1, 0, 0]) cube([10, 20, 5]);
// Reflejar en diagonal
mirror([1, 1, 0]) cube([10, 20, 5]);
\end{openscad}

\section{\codigo{color("nombre")} --- Color para preview}
Asigna color a los hijos (solo Preview F5):
\begin{openscad}
color("RoyalBlue") cube([10, 10, 10]);
color([1.0, 0.5, 0]) sphere(r = 5);      // RGB [0-1]
color("LightGray", 0.5) cube([20, 5, 5]); // Semitransparente
\end{openscad}

\section{\codigo{resize([x, y, z])} --- Redimensionar}
Fuerza dimensiones absolutas, a diferencia de \codigo{scale()}:
\begin{openscad}
// Esfera de radio 10 -> elipsoide de 30x60x10
resize([30, 60, 10]) sphere(r = 10);
\end{openscad}

\section{Composicion: se lee de adentro hacia afuera}
\begin{openscad}
translate([30, 0, 0])
    rotate([0, 0, 45])
        cube([10, 10, 10]);
\end{openscad}

\section{Caso Real: Rotaciones y traslaciones}
En \codigo{cad/cuerpo\_cuadruepdo.scad}:
\begin{openscad}
for (a = [45, 135, 225, 315]) {
    rotate([0, 0, a])
        translate([cuerpo_r - 7, 0, cuerpo_t/2])
            rotate([0, 0, -90])
                soporte_servo_cadera();
}
\end{openscad}

\section{Caso Real 2: Codigo de colores}
En \codigo{cad/ensamble\_cuadruepodo.scad}:
\begin{openscad}
module dummy_servo() {
    color("RoyalBlue") {
        cube([12.5, 23.0, 22.5], center=true);
    }
    color("White") {
        translate([0, 5.5, 14])
            cylinder(r=6, h=1.5, center=true);
    }
}
\end{openscad}

% ═════════════════════════════════════════════════════════════════════════════
% CAPÍTULO 3
% ═════════════════════════════════════════════════════════════════════════════
\chapter{Operaciones Booleanas (El Corazon del Diseno)}

Las operaciones booleanas combinan solidos para crear formas complejas.

\section{\codigo{union()}}
Fusiona todos los hijos en un solo solido:
\begin{openscad}
union() {
    cube([10, 10, 10]);
    translate([5, 5, 0])
        cylinder(r = 5, h = 10);
}
\end{openscad}

\section{\codigo{difference()}}
Resta los hijos subsiguientes del primero:
\begin{openscad}
difference() {
    cube([20, 20, 10], center=true);
    translate([0, 0, -1])
        cylinder(r = 3, h = 12);
}
\end{openscad}

\section{\codigo{intersection()}}
Devuelve solo el volumen compartido:
\begin{openscad}
intersection() {
    sphere(r = 10);
    cube([10, 10, 10], center=true);
}
\end{openscad}

\section{Anidamiento}
Las booleanas se anidan sin limite:
\begin{openscad}
difference() {
    union() {
        cylinder(r = 20, h = 5);
        translate([15, 0, 0])
            cube([10, 10, 5], center=true);
    }
    cylinder(r = 3, h = 10, center=true);
}
\end{openscad}

\section{Caso Real: El soporte de servo}
El modulo \codigo{soporte\_servo\_cadera()} en \codigo{cad/cuerpo\_cuadruepdo.scad}:

\begin{openscad}
module soporte_servo_cadera() {
    difference() {
        // SOLIDO BASE
        translate([0, 0, 7.5])
            cube([36, 28, 15], center=true);
        // 1. Cavidad dual-depth para servo SG90
        translate([0, 0, 2.9])
            cube([30.0, 24.2, 4.2], center=true);
        translate([0, 0, 9.5])
            cube([25.0, 24.2, 9.0], center=true);
        // 2. Ranura para bridas
        translate([0, 5.5, 7.5])
            cube([34.5, 3.2, 13.5], center=true);
        // 3. Agujeros pasantes para tornillos M2
        translate([-14.25, 0, 7.5])
            rotate([90, 0, 0])
                cylinder(r=1.0, h=35, center=true);
        translate([14.25, 0, 7.5])
            rotate([90, 0, 0])
                cylinder(r=1.0, h=35, center=true);
        // 4. Abertura para corona de salida
        translate([5.5, 12.0, 7.5])
            rotate([90, 0, 0])
                cylinder(r=6.2, h=15, center=true);
        // 5. Rebaje para rotacion del femur
        translate([6.5, 12.0, 7.5])
            cube([23, 5, 16], center=true);
    }
}
\end{openscad}

\textbf{Dual-depth pocket:} la cavidad tiene dos anchos (30mm abajo para cables, 25mm arriba para rosca de tornillos M2).

% ═════════════════════════════════════════════════════════════════════════════
% CAPÍTULO 4
% ═════════════════════════════════════════════════════════════════════════════
\chapter{Variables y Parametros}

\section{Declaracion y asignacion}
En \openscadlogo\ las variables se asignan con \codigo{=} y son \textbf{inmutables}:
\begin{openscad}
ancho = 20; profundidad = 30; alto = 10;
cube([ancho, profundidad, alto]);
\end{openscad}

\section{Variables parametricas}
\begin{openscad}
longitud = 50; ancho = 20; altura = 10;
pared = 2.0; tornillo_r = 1.5;

difference() {
    cube([longitud, ancho, altura]);
    translate([pared, pared, -1])
        cube([longitud - 2*pared, ancho - 2*pared, altura + 2]);
}
\end{openscad}

\section{\codigo{let()} --- Variables locales}
\begin{openscad}
let (ancho = 30, largo = ancho * 1.5) {
    cube([ancho, largo, 5]);
}
\end{openscad}

\section{\codigo{assert()} --- Validacion}
\begin{openscad}
module soporte(alto, ancho) {
    assert(alto > 0, "El alto debe ser positivo");
    assert(ancho > 0, "El ancho debe ser positivo");
    cube([ancho, ancho, alto]);
}
\end{openscad}

\section{\codigo{function} --- Funciones definidas por el usuario}
\begin{openscad}
function area_circulo(radio) = PI * radio * radio;
function volumen_cilindro(radio, alto) = area_circulo(radio) * alto;
echo(volumen_cilindro(10, 20));  // 6283.19
\end{openscad}

\section{Funciones de string y lista}
\begin{openscad}
// str() - convertir a string
etiqueta = str("Pieza-", 3, ".stl");  // "Pieza-3.stl"
// concat() - unir listas
c = concat([1, 2, 3], [4, 5]);       // [1, 2, 3, 4, 5]
// len() - longitud
largo = len([10, 20, 30]);           // 3
\end{openscad}

\section{Operador ternario}
\begin{openscad}
usar_agujeros = true;
resolucion = (usar_agujeros ? 50 : 20);
\end{openscad}

\section{Constantes especiales}
\begin{openscad}
radio = 10;
circunferencia = 2 * PI * radio;  // 62.8318
echo(circunferencia);
\end{openscad}

\section{Caso Real: Variables parametricas del SpiderBot}
En \codigo{cad/eslabon\_pata\_cuadrupedo.scad}:
\begin{openscad}
link_len = 55.0; // Longitud entre cadera y rodilla
link_h = 25.0;   // Altura extremo de rodilla
link_t = 16.0;   // Grosor bloque servo rodilla
servo_w = 23.0;  servo_t = 12.5;
servo_h = 22.5;  ear_dist = 28.5;
\end{openscad}

Si cambias \codigo{link\_len = 55} a \codigo{70}, el bolsillo del servo y la abertura del engranaje se desplazan automaticamente.

% ═════════════════════════════════════════════════════════════════════════════
% CAPÍTULO 5
% ═════════════════════════════════════════════════════════════════════════════
\chapter{Modulos --- Funciones del Diseno Parametrico}

\section{Sintaxis basica}
\begin{openscad}
module nombre(param1, param2 = valor_defecto) {
    // Geometria aqui
}
\end{openscad}

\section{Ejemplo: tornillo parametrico}
\begin{openscad}
module tornillo(longitud, diametro = 4) {
    radio = diametro / 2;
    cylinder(r = radio, h = longitud);
    translate([0, 0, longitud])
        cylinder(r = radio * 1.5, h = 3);
}
tornillo(20);                   // L=20, D=4
tornillo(30, 6);                // L=30, D=6
tornillo(diametro=5, longitud=15);  // Argumentos nombrados
\end{openscad}

\section{\codigo{children()} --- Modulos que envuelven geometria}
\begin{openscad}
module envolvente(radio_borde = 2) {
    minkowski() {
        children();  // Toma lo que se pase entre llaves
        sphere(r = radio_borde);
    }
}
envolvente(3) {
    cube([20, 20, 5], center=true);
}
\end{openscad}

\section{DRY en CAD}
\begin{openscad}
// MAL: codigo duplicado
cube([10, 20, 5]);
translate([15, 0, 0]) cube([10, 20, 5]);

// BIEN: con modulo
module bloque() { cube([10, 20, 5]); }
bloque();
translate([15, 0, 0]) bloque();
\end{openscad}

\section{Caso Real: Los modulos del SpiderBot}
\begin{openscad}
module soporte_servo_cadera() { ... }   // bracket de cadera
module placa_base_cuadruepodo() { ... } // chasis inferior
module placa_superior() { ... }         // chasis superior con cunas
module eslabon_completo() { ... }       // femur completo
module tibia() { ... }                  // pierna inferior

// Composicion en ensamble_cuadruepodo.scad:
module pata_articulada(angulo_cadera=0, angulo_rodilla=0) {
    dummy_servo();
    rotate([0, angulo_cadera, 0])
        eslabon_completo();
    translate([55, 2.75, 0])
        rotate([0, angulo_rodilla, 0])
            tibia();
}
\end{openscad}

% ═════════════════════════════════════════════════════════════════════════════
% CAPÍTULO 6
% ═════════════════════════════════════════════════════════════════════════════
\chapter{Iteracion y Simetria --- El Bucle \codigo{for}}

\section{Sintaxis}
\begin{openscad}
for (i = [0 : 1 : 5]) {             // Rango [inicio:incremento:fin]
    translate([i * 10, 0, 0])
        cube([5, 5, 5]);
}
for (i = [10, 20, 30, 50]) { ... }  // Lista explicita
\end{openscad}

\section{Distribucion radial}
\begin{openscad}
for (angulo = [0 : 60 : 300]) {
    rotate([0, 0, angulo])
        translate([40, 0, 0])
            cylinder(r = 2, h = 10, center=true);
}
\end{openscad}

\section{\codigo{intersection\_for()}}
\begin{openscad}
intersection_for(n = [0 : 5]) {
    rotate([0, 0, n * 60])
        translate([5, 0, 0])
            cylinder(r = 3, h = 10);
}
\end{openscad}

\section{List Comprehensions}
\begin{openscad}
cuadrados = [for (i = [0:10]) i * i];
pares = [for (i = [0:20]) if (i % 2 == 0) i];
\end{openscad}

\section{Caso Real: Las 4 patas del SpiderBot}
\begin{openscad}
// Distribuye 4 soportes en 45, 135, 225, 315 grados
for (a = [45, 135, 225, 315]) {
    rotate([0, 0, a])
        translate([cuerpo_r - 7, 0, cuerpo_t/2])
            rotate([0, 0, -90])
                soporte_servo_cadera();
}

// Agujeros de pilares (0, 90, 180, 270 grados)
for (a = [0, 90, 180, 270]) {
    rotate([0, 0, a])
        translate([spacer_r, 0, 0])
            cylinder(r=1.6, h=cuerpo_t+2, center=true);
}

// For anidado para pasacables
for (x = [-40, 40]) {
    for (y = [-39, 39]) {
        translate([x, y, 0])
            cylinder(r=7.0, h=30, center=true);
    }
}
\end{openscad}

% ═════════════════════════════════════════════════════════════════════════════
% CAPÍTULO 7
% ═════════════════════════════════════════════════════════════════════════════
\chapter{Operaciones Avanzadas}

\section{\codigo{hull()} --- Envolvente convexa}
\begin{openscad}
hull() {
    sphere(r = 10);
    translate([30, 0, 0])
        sphere(r = 8);
}
\end{openscad}
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

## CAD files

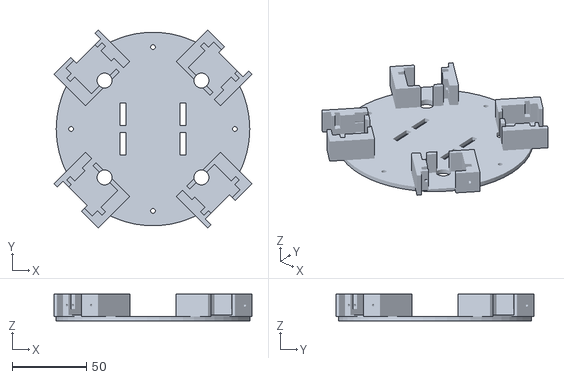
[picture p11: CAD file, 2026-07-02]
cad/placa_base_inferior.stl
132.9 x 132.9 x 18.0

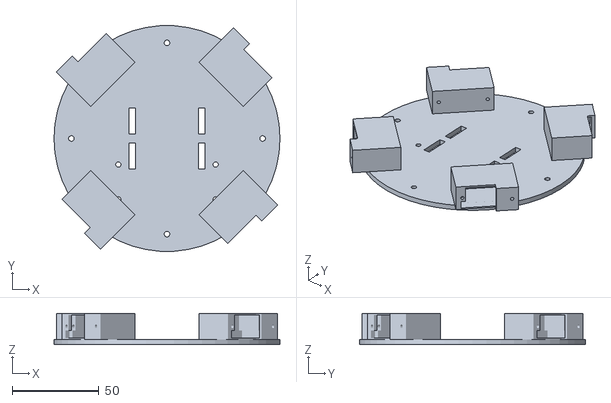
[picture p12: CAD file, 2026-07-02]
cad/cuerpo_cuadruepdo.stl
130.0 x 129.7 x 18.0

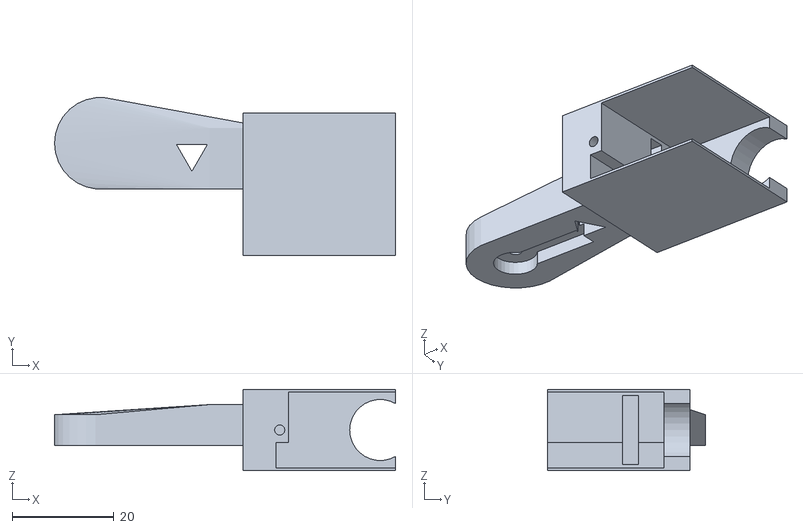
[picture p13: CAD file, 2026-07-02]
cad/eslabon_pata_cuadrupedo.stl
67.0 x 31.0 x 16.0

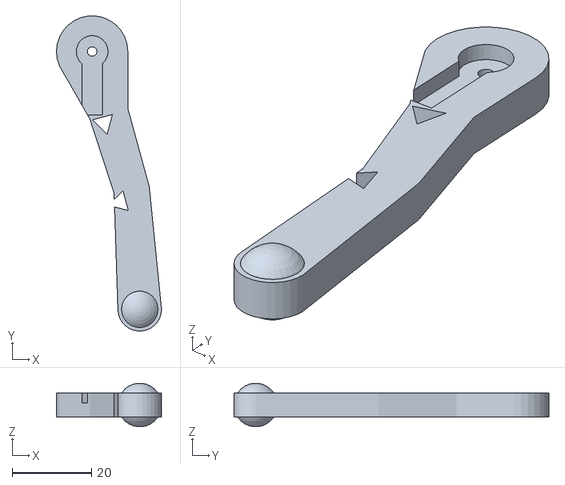
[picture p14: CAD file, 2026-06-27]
cad/tibia_inferior.stl
26.5 x 79.4 x 10.9

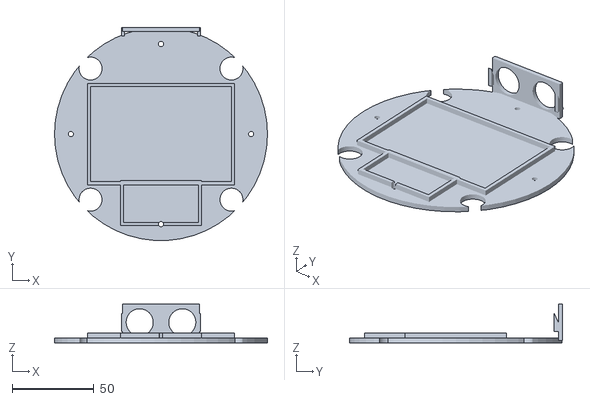
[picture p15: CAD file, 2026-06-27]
cad/placa_base_superior.stl
130.0 x 129.9 x 23.5

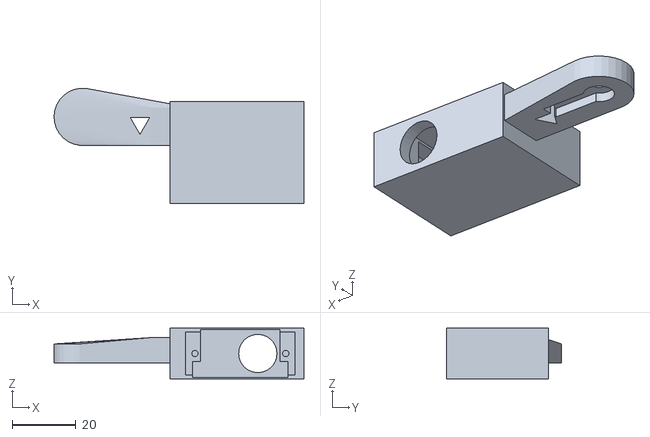
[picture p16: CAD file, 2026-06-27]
cad/eslabon_femur.stl
78.5 x 36.2 x 16.0

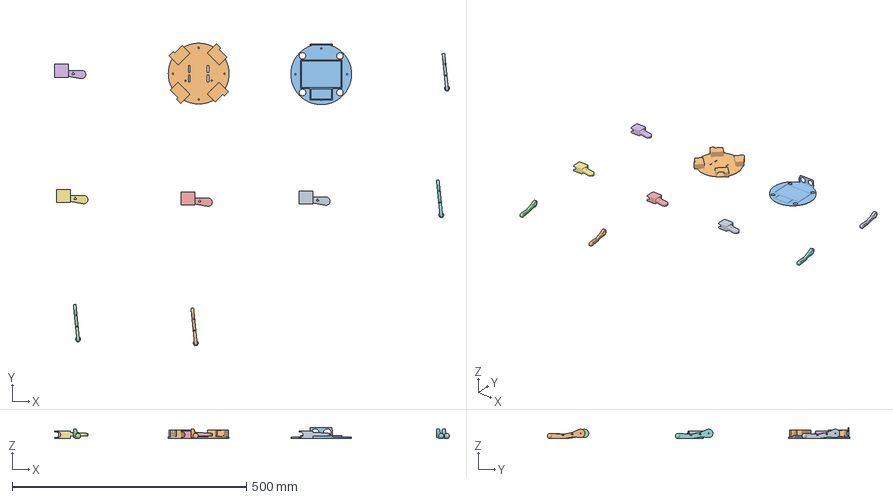
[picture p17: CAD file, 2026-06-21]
cad/spiderbot.3mf
843.1 x 645.7 x 23.5 mm
eslabon_femur.stl x 4
placa_base_inferior.stl
placa_base_superior.stl
tibia_inferior.stl x 4

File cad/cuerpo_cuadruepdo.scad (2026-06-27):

// Cuerpo Central del Cuadrúpedo (USS SpiderBot)
// Diseño de Doble Deck (Placa Superior e Inferior) en Configuración Pitch-Pitch
// Taller de Programación I - Solemne 3

$fn = 50;

cuerpo_r = 65.0;    // Radio del chasis circular
cuerpo_t = 3.0;     // Grosor de las placas
spacer_r = 55.0;    // Radio para pilares espaciadores

module soporte_servo_cadera() {
    difference() {
        // Bloque estructural principal (ensanchado a 30mm de ancho y 42mm de largo para mayor grosor de pared)
        translate([0, 0, 7.5])
            cube([42, 30, 15], center=true);
        
        // 1. Cavidad para el cuerpo del servo SG90 (tolerancias ajustadas)
        // Reducimos el largo de la cavidad inferior a 25.0mm para dar soporte sólido a los tornillos
        translate([0, 0, 2.9])
            cube([25.0, 24.2, 4.2], center=true);
        translate([0, 0, 15.0])
            cube([25.0, 24.2, 20.0], center=true);
            
        // 2. Ranura para las orejas/bridas del servo (Y = 5.5, ancho = 3.5, largo = 33.5 para mayor resistencia de pared)
        translate([0, 5.5, 15.0])
            cube([33.5, 3.5, 20.0], center=true);
            
        // 3. Agujeros para los tornillos M2 (pasantes en Y, alineados a Y = 5.5 para encajar con las orejas del servo)
        translate([-14.25, 5.5, 7.5])
            rotate([90, 0, 0])
                cylinder(r=1.0, h=35, center=true);
        translate([14.25, 5.5, 7.5])
            rotate([90, 0, 0])
                cylinder(r=1.0, h=35, center=true);
                   
        // 4. Abertura delantera (Y+) para corona de salida del servo
        translate([5.5, 12.0, 7.5])
            rotate([90, 0, 0])
                cylinder(r=6.2, h=15, center=true);
                
        // 4b. Ranura superior para permitir deslizar el eje del servo desde arriba al ensamblar
        translate([5.5, 12.0, 11.25])
            cube([12.4, 15, 7.5], center=true);
                
        // 5. Rebaje frontal-derecho para rotación libre del fémur
        // Ensanchamos a Y=6.0 y lo trasladamos a Y=12.5 para eliminar paredes delgadas flotantes
        translate([6.5, 12.5, 7.5])
            cube([23, 6, 16], center=true);

        // 6. Agujero para paso de cables en el piso y pared posterior (local Y = -12, X = 0)
        translate([0, -12, 7.5])
            cylinder(r=5.0, h=16, center=true);
            
        // 7. Canal de cable en el extremo derecho (X+) y lado posterior (Y-)
        // Permite enrutar el cable que sale del lado del servo hacia el canal central
        translate([13.0, -10.5, 7.5])
            cube([4.0, 9.0, 16.0], center=true);
    }
}

module placa_base_cuadruepodo() {
    difference() {
        // Placa inferior sólida
        cylinder(r = cuerpo_r, h = cuerpo_t, center=true);
        
        // Agujeros para los 4 pilares espaciadores M3
        for (a = [0, 90, 180, 270]) {
            rotate([0, 0, a])
                translate([spacer_r, 0, 0])
                    cylinder(r=1.6, h=cuerpo_t+2, center=true);
        }
        
        // Ranuras para amarras de velcro para la batería Li-ion 2S
        translate([-20, -10, 0]) cube([4, 15, cuerpo_t + 2], center=true);
        translate([20, -10, 0]) cube([4, 15, cuerpo_t + 2], center=true);
        translate([-20, 10, 0]) cube([4, 15, cuerpo_t + 2], center=true);
        translate([20, 10, 0]) cube([4, 15, cuerpo_t + 2], center=true);
        


        // Agujeros para pasar los cables de los servos en la parte trasera de cada bracket (radio 46mm)
        for (a = [45, 135, 225, 315]) {
            rotate([0, 0, a])
                translate([46, 0, 0])
                    cylinder(r=5.0, h=cuerpo_t+2, center=true);
        }
    }
    
    // Añadir los 4 soportes de servo de cadera en la periferia (orientados tangencialmente, eje hacia afuera)
    // Traslación corregida a cuerpo_r - 7 para compensar el ensanchamiento a 28mm
    for (a = [45, 135, 225, 315]) {
        rotate([0, 0, a])
            translate([cuerpo_r - 7, 0, cuerpo_t/2])
                rotate([0, 0, -90])
                    soporte_servo_cadera();
    }
}

module placa_superior() {
    difference() {
        // ── ESTRUCTURA SÓLIDA (UNION) ─────────────────────────────────
        union() {
            // Placa superior circular principal
            cylinder(r = cuerpo_r, h = cuerpo_t, center=true);
            
            // Cuna para Protoboard de 400 puntos en el centro (0,0) (enlarged by 2mm: 86.0mm x 58.0mm)
            translate([0, 0, cuerpo_t/2 + 1.5]) {
                difference() {
                    cube([90.0, 62.0, 3.0], center=true);
                    cube([86.0, 58.0, 3.1], center=true);
                }
            }
            
            // Cuna para Regulador XL6009E1 desplazado al área trasera (X = 0, Y = -42) (enlarged by 2mm: 45.6mm x 23.6mm)
            translate([0, -42, cuerpo_t/2 + 1.5]) {
                difference() {
                    cube([49.6, 27.6, 3.0], center=true);
                    cube([45.6, 23.6, 3.1], center=true);
                }
            }
            
            // Soporte integrado vertical frontal para Sonar HC-SR04
            // Colocado en el borde frontal (Y = cuerpo_r - 1.25)
            // Dimensiones: 47mm de ancho, 2.5mm de espesor, 22mm de altura.
            translate([0, cuerpo_r - 1.25, 11]) {
                cube([47.0, 2.5, 22.0], center=true);
            }
            
            // Gussets/Refuerzos triangulares de soporte lateral (en X = +/- 22.25)
            translate([-22.25, cuerpo_r - 5.0, 5.5]) {
                rotate([0, -90, 0])
                    linear_extrude(height = 2.0)
                        polygon(points = [[0, 0], [11, 0], [0, 5]]);
            }
            translate([24.25, cuerpo_r - 5.0, 5.5]) {
                rotate([0, -90, 0])
                    linear_extrude(height = 2.0)
                        polygon(points = [[0, 0], [11, 0], [0, 5]]);
            }
        }
        
        // ── AGUJEROS Y CORTES (DIFFERENCE) ───────────────────────────
        
        // 1. Agujeros para pilares espaciadores M3
        for (a = [0, 90, 180, 270]) {
            rotate([0, 0, a])
                translate([spacer_r, 0, 0])
                    cylinder(r=1.6, h=30, center=true);
        }
        
        // 2. Orificios para los transductores ("ojos") del HC-SR04 (16.5mm diámetro, espaciados 26mm)
        translate([-13, cuerpo_r - 1.25, 11])
            rotate([90, 0, 0])
                cylinder(r=8.25, h=10, center=true);
        translate([13, cuerpo_r - 1.25, 11])
            rotate([90, 0, 0])
                cylinder(r=8.25, h=10, center=true);
                 
        // 3. Orificios de paso de cables (wire routing) en las 4 esquinas de la cuna (shifted outward to clear cuna)
        for (x = [-43, 43]) {
            for (y = [-40, 40]) {
                translate([x, y, 0])
                    cylinder(r=7.0, h=30, center=true);
            }
        }
    }
}

placa_base_cuadruepodo();

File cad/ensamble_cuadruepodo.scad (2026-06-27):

// Ensamble Visual Completo del USS SpiderBot en OpenSCAD
// Configuración Rígida Pitch-Pitch (2 Ejes de Rotación Horizontal)
// Taller de Programación I - Solemne 3

use <cuerpo_cuadruepdo.scad>
use <eslabon_pata_cuadrupedo.scad>
use <tibia_pata.scad>

$fn = 20;

cuerpo_r = 65.0;
deck_spacing = 28.0;

module dummy_servo() {
    // Renderizado simplificado de un servomotor SG90
    color("RoyalBlue") {
        cube([12.5, 23.0, 22.5], center=true);
        translate([0, 0, 5.5])
            cube([12.5, 32.5, 2.5], center=true);
        translate([0, 5.5, 12])
            cylinder(r=2.5, h=4, center=true);
    }
    color("White") {
        translate([0, 5.5, 14])
            cylinder(r=6, h=1.5, center=true);
    }
}

module pilar_espaciador() {
    color("Silver")
        cylinder(r=3.5, h=deck_spacing - 3, center=true);
}

module pata_articulada(angulo_cadera=0, angulo_rodilla=0) {
    // 1. Servo de cadera (Hip Pitch) - Montado horizontalmente en el soporte perimetral
    // Rotado [90, -90, 180] para meterse en la cavidad y orientar el eje a Y+ (X=5.5, Y=14.0, Z=7.5)
    translate([0, 0, 7.5])
        rotate([90, -90, 180])
            dummy_servo();
            
    // 2. Eslabón Fémur - Gira verticalmente (angulo_cadera) acoplado al eje del servo cadera
    // El eje real de la corona de salida está en X=5.5, Y=14.0, Z=7.5
    translate([5.5, 14.0, 7.5]) {
        rotate([0, angulo_cadera, 0]) {
            // Rotación correctiva del fémur de 90 en X para que apunte hacia abajo (en XZ)
            // y la tibia apunte al suelo (Z-)
            rotate([90, 0, 0]) {
                color("DarkSlateGray")
                    eslabon_completo(); // El origen del fémur está en su eje de giro
                    
                // 3. Servo de rodilla (Knee Pitch) - Montado horizontalmente dentro del fémur
                // Orientado y alineado con el eje físico de rotación en X = 55 (rodilla), Y = 2.75, Z = 0
                translate([55 - 5.5, -11.25, 0])
                    rotate([90, -90, 180])
                        dummy_servo();
                        
                // 4. Tibia - Gira verticalmente (angulo_rodilla) acoplada al horn del servo de rodilla
                translate([55, 2.75, 0]) {
                    rotate([0, angulo_rodilla, 0]) {
                        rotate([90, 0, 0]) { // Alinear la tibia verticalmente hacia abajo
                            color("Black")
                                tibia();
                        }
                    }
                }
            }
        }
    }
}

module ensamble_completo() {
    // 1. Placa Base Inferior con soportes de servo integrados
    color("Black") placa_base_cuadruepodo();
    
    // 2. Pilares espaciadores
    for (a = [0, 90, 180, 270]) {
        rotate([0, 0, a])
            translate([55, 0, deck_spacing/2])
                pilar_espaciador();
    }
    
    // 3. Placa Superior
    color("Black")
        translate([0, 0, deck_spacing])
            placa_superior();
            
    // Protoboard de 400 puntos en el centro
    color("LightGray")
        translate([0, 0, deck_spacing + 6.0])
            cube([84.0, 56.0, 9.0], center=true);
            
    // ESP32 DevKit V1 (38 pines) pinchada en la protoboard
    color("Silver")
        translate([0, 0, deck_spacing + 10.5 + 2.0])
            cube([28.0, 51.5, 4], center=true);
            
    // MPU6050 (GY-521) pinchada en la protoboard
    color("DarkBlue")
        translate([-20, 10, deck_spacing + 10.5 + 1.5])
            cube([21.2, 16.4, 3], center=true);
            
    // Convertidor XL6009E1 en su cuna trasera
    color("Navy")
        translate([0, -42, deck_spacing + 5.5])
            cube([43.0, 21.0, 8], center=true);
            
    // Sensor de Ultrasonido HC-SR04
    color("CadetBlue")
        translate([0, cuerpo_r - 2.5, deck_spacing + 11])
            rotate([90, 0, 0])
                cube([45.0, 20.0, 2], center=true);
    color("Silver") {
        translate([-13, cuerpo_r - 7.5, deck_spacing + 11])
            rotate([90, 0, 0])
                cylinder(r=8.0, h=10, center=true);
        translate([13, cuerpo_r - 7.5, deck_spacing + 11])
            rotate([90, 0, 0])
                cylinder(r=8.0, h=10, center=true);
    }
            
    // 5. Las 4 Patas montadas en los soportes perimetrales (a 45, 135, 225, 315 grados)
    for (a = [45, 135, 225, 315]) {
        rotate([0, 0, a])
            translate([cuerpo_r - 7, 0, 1.5]) // Centrado exacto con el soporte de servo de cadera (cuerpo_r - 7)
                rotate([0, 0, -90])     // Rotar para alinear con el bracket perimetral (eje hacia afuera)
                    pata_articulada(15, -45); // Pose de pie
    }
}

ensamble_completo();

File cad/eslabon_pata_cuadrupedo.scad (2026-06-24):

// Eslabón de Pata (Fémur) para USS SpiderBot
// Diseñado para albergar el servo de rodilla (Knee Pitch) horizontalmente
// Taller de Programación I - Solemne 3

$fn = 30;

link_len = 55.0; // Longitud entre la cadera y la rodilla
link_h = 25.0;   // Altura en el extremo de la rodilla para sostener el servo
link_t = 16.0;   // Grosor del bloque del servo rodilla (brinda soporte lateral)

// Dimensiones del servo SG90
servo_w = 23.0;
servo_t = 12.5;
servo_h = 22.5;
ear_dist = 28.5;

module eslabon_completo() {
    difference() {
        // Estructura principal del fémur
        union() {
            // Brazo conector desde la cadera
            hull() {
                // Junta de cadera (acople al horn del servo cadera)
                cylinder(r = 9, h = 6, center=true);
                // Transición al bloque del servo (alineado a Z=-3 para base plana)
                translate([link_len/2, -3, 1])
                    cube([12, 12, 8], center=true);
            }
            // Bloque que aloja el servo de rodilla (al final del fémur, centrado simétricamente con el bolsillo para mayor grosor de pared)
            translate([link_len - 6.5, -11.25, 0])
                cube([42, 32, link_t], center=true);
        }
        
        // 1. Acople para el horn del servo Cadera (Hip Pitch) en el origen (X=0, Z = -1.8)
        // Tallado en la cara inferior (Z-) que mira hacia el cuerpo del robot
        translate([0, 0, -1.8]) {
            cylinder(r=4.0, h=2.6, center=true);
            translate([8.0, 0, 0])
                cube([16.0, 5.2, 2.6], center=true);
            cylinder(r=1.2, h=10, center=true);
        }
        
        // 2. Bolsillo (pocket) para el servo de Rodilla (Knee Pitch) (dual-depth para cables y soporte de tornillos, abierto hacia atrás Y- para inserción)
        // Se coloca de forma que el eje del servo coincida exactamente con X = link_len (55)
        translate([link_len - 5.5, -11.25, 0]) {
            // Parte inferior ensanchada a 30.0mm para cables (Z = -7.5 a -2.5, extendida en Y- para cortar la cara posterior)
            translate([0, -5.4, -5.0])
                cube([30.0, 35.0, 5.0], center=true);
            // Parte superior estrecha a 25.0mm para soporte roscado (Z = -2.5 to 7.5, extendida en Y- para cortar la cara posterior)
            translate([0, -5.4, 2.5])
                cube([25.0, 35.0, 10.0], center=true);
            
            // Ranura para orejas/bridas (paralela a XZ, extendida en Y- desde el soporte de la oreja hasta atrás)
            translate([0, -5.4, 0])
                cube([34.5, 25.0, 13.5], center=true);
                
            // Agujeros para tornillos de orejas (paso estandar de 28.5mm)
            translate([-14.25, 0, 0])
                rotate([90, 0, 0])
                    cylinder(r=1.0, h=30, center=true);
            translate([14.25, 0, 0])
                rotate([90, 0, 0])
                    cylinder(r=1.0, h=30, center=true);
        }
        
        // 3. Abertura delantera (Y+) para que sobresalga el engranaje del servo de rodilla (en X=55)
        translate([link_len, 0, 0])
            rotate([90, 0, 0])
                cylinder(r=6, h=35, center=true);
                
        // 4. Alivios de peso estéticos triangulares en el brazo
        translate([18, -2, 0])
            rotate([0, 0, 30])
                cylinder(r=3.5, h=10, $fn=3, center=true);
    }
}

eslabon_completo();

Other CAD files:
cad/tibia_pata.stl
cad/placa_base_inferior.scad
cad/placa_base_superior.scad
cad/tibia_pata.scad

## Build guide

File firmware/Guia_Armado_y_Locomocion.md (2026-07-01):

# Manual Definitivo de Armado, Electrónica, Locomoción y Firmware — USS SpiderBot (4-DoF)
**Solemne 3 — Taller de Programación I (Universidad San Sebastián, 2026)**

Este documento constituye la guía oficial y definitiva para el ensamblaje mecánico, la integración de la electrónica regulada, el conexionado físico (pinout), el centrado de servomotores y la calibración inercial del robot cuadrúpedo **USS SpiderBot** simplificado a una configuración de **4 servomotores (4-DoF)**. Además, se detalla la arquitectura de software (MicroPython) y el funcionamiento de la Inteligencia Artificial Sensorial embebida.

---

## 💻 Índice
1. [Especificaciones y Arquitectura General](#1-especificaciones-y-arquitectura-general)
2. [Lista de Materiales y Herramientas (BOM)](#2-lista-de-materiales-y-herramientas-bom)
3. [Integración Eléctrica y Regulación de Potencia](#3-integración-eléctrica-y-regulación-de-potencia)
4. [Pinout y Diagrama de Cableado Detallado](#4-pinout-y-diagrama-de-cableado-detallado)
5. [Guía de Ensamblaje Mecánico 3D Paso a Paso](#5-guía-de-ensamblaje-mecánico-3d-paso-a-paso)
6. [Estructura del Firmware y Mapa de Archivos](#6-estructura-del-firmware-y-mapa-de-archivos)
7. [Algoritmo de Locomoción y Marcha de Gateo](#7-algoritmo-de-locomoción-y-marcha-de-gateo)
8. [Inteligencia Artificial Sensorial (IA Local)](#8-inteligencia-artificial-sensorial-ia-local)
9. [Protocolo de Puesta en Marcha y Calibración](#9-protocolo-de-puesta-en-marcha-y-calibración)
10. [Guía de Diagnóstico y Resolución de Problemas (FAQ)](#10-guía-de-diagnóstico-y-resolución-de-problemas-faq)

---

## 1. Especificaciones y Arquitectura General
El **USS SpiderBot** es un robot móvil terrestre cuadrúpedo articulado con **4 grados de libertad (4-DoF)**. Su diseño físico simplificado cuenta con **un único servomotor por pata**, posicionado en la articulación de la cadera o *Coxa*. La articulación de la rodilla (*Fémur*) se mantiene en un ángulo rígido fijo de $90^\circ$ (perpendicular), lo que reduce considerablemente el peso, el consumo eléctrico y la complejidad del cableado, permitiendo una locomoción robusta basada en deslizamiento y fricción controlada.

### Características Principales:
*   **Microcontrolador Principal:** ESP32 DevKit V1 ejecutando MicroPython asíncrono.
*   **Locomoción Dinámica:** Marcha de gateo oscilante de 4 fases actuando únicamente sobre las caderas.
*   **Seguridad Reactiva:** Sensor de proximidad ultrasónico HC-SR04 y buzzer activo de alarma.
*   **IA de Borde (Edge AI):** Clasificador embebido local (MPU6050) para detectar caídas, derrapes y perturbaciones externas.
*   **Interfaz de Operación:** Servidor web asíncrono y control inalámbrico mediante dashboard Glassmorphism por Wi-Fi.

---

## 2. Lista de Materiales y Herramientas (BOM)

### A. Componentes Electrónicos
*   **1x ESP32 DevKit V1 (38 pines):** Microcontrolador principal de 3.3V.
*   **4x Servomotores SG90 (engranajes de nylon) o MG90S (engranajes metálicos):** Actuadores de cadera.
*   **1x Módulo GY-521 (IMU MPU6050):** Acelerómetro y giroscopio de 6 ejes con comunicación I2C.
*   **1x Sensor Ultrasónico HC-SR04:** Transductor de distancia de 5V.
*   **1x Buzzer Activo (5V):** Generador de alertas acústicas.
*   **2x Convertidores Step-Down LM2596:** Reguladores reductores de voltaje ajustables (LM2596 #1 para servos, LM2596 #2 para lógica).
*   **2x Porta Pilas Duales 2x18650:** Dos packs independientes de 2 celdas en serie.
*   **4x Celdas de Litio-Ion 18650:** Baterías recargables.

### B. Materiales de Chasis e Impresión 3D
*   **1x Placa Base Inferior (`cuerpo_cuadruepdo.scad`):** Soporta servos de cadera y portabaterías.
*   **1x Placa Base Superior/Tapa (`cuerpo_cuadruepdo.scad`):** Protege la electrónica y soporta la ESP32.
*   **4x Extremidades Rígidas:** Conjunto de fémur y tibia fijos mecánicamente a $90^\circ$ (o patas rígidas de una sola pieza).
*   **4x Pilares Separadores:** Pilares de 25mm M3 para distanciar el chasis.

---

## 3. Integración Eléctrica y Regulación de Potencia

Al reducir los servomotores a 4 unidades, el consumo máximo del sistema disminuye a aproximadamente **1.5A** en picos mecánicos. Esto permite simplificar la electrónica utilizando **un único convertidor step-down LM2596 regulado a 5.0V** y **un único portapilas dual 18650** para alimentar en paralelo tanto la lógica de control como los actuadores:

```text
  [Pack Batería (7.4V)] ──> [LM2596 (Regulado a 5.0V)] ──> Riel VCC (5.0V Común)
                                                          ├──> Pin Vin ESP32 y Sensores
                                                          └──> Riel VCC Servomotores (Servos 0-3)
```

### 🛠️ Protocolo Obligatorio de Regulación:
1.  **Ajuste Inicial:** Use un multímetro para ajustar la salida del **LM2596 a exactamente 5.0V** antes de conectar la ESP32 o los servos.
2.  **Masa Común (GND):** Conecte el pin GND de la ESP32, la tierra de salida del LM2596 y la tierra de los servos en el mismo riel común.
3.  **Prevención de Retorno (USB + Baterías):** **Nunca** encienda la alimentación de la batería lógica (que entrega voltaje a `Vin`) mientras la ESP32 esté conectada al puerto USB del PC. Para cargar código, apague las baterías. Para pruebas, desconecte el USB.

---

## 4. Pinout y Diagrama de Cableado Detallado

El conexionado físico de la ESP32 DevKit V1 se reduce a **4 canales PWM directos** para los servomotores:

| Pin ESP32 | Componente | Tipo de Señal | Función / Descripción |
| :---: | :--- | :---: | :--- |
| **Vin** | Salida LM2596 (5.0V) | Alimentación IN | Entrada de voltaje regulado para la lógica de la ESP32 |
| **GND** | Nodo de Tierra Común | Referencia | Tierra unificada del sistema |
| **GPIO 21** | MPU6050 (IMU) | SDA (I2C) | Bus de datos serie de la unidad inercial |
| **GPIO 22** | MPU6050 (IMU) | SCL (I2C) | Bus de reloj serie de la unidad inercial |
| **GPIO 18** | HC-SR04 (Sonar) | TRIGGER | Pulso digital de disparo del ultrasonido |
| **GPIO 19** | HC-SR04 (Sonar) | ECHO | Entrada de lectura del tiempo de eco |
| **GPIO 14** | Buzzer Activo | Salida Digital | Activación y modulación de tonos acústicos |
| **GPIO 23** | Servo FR - Coxa (Canal 0) | Salida PWM | Articulación cadera delantera derecha |
| **GPIO 17** | Servo FL - Coxa (Canal 1) | Salida PWM | Articulación cadera delantera izquierda |
| **GPIO 15** | Servo RL - Coxa (Canal 2) | Salida PWM | Articulación cadera trasera izquierda |
| **GPIO 13** | Servo RR - Coxa (Canal 3) | Salida PWM | Articulación cadera trasera derecha |

---

## 5. Guía de Ensamblaje Mecánico 3D Paso a Paso

El ensamblaje para 4-DoF simplifica el proceso al omitir la electrónica articulada en las rodillas:

1.  **Montaje de Servos en Chasis:** Inserte a presión los 4 servomotores en sus soportes perimetrales en la **Placa Base Inferior**. El eje estriado debe mirar hacia el extremo exterior. Asegúrelos con tornillos autorroscantes M2.
2.  **Calibración del Cero Eléctrico (Paso Crítico):** Conecte la ESP32 por USB y ejecute `prueba_servos.py` seleccionando la **Opción 3** para forzar a todos los servos a la posición neutra de **$90^\circ$**.
3.  **Montaje de Patas Rígidas:** Con los servos energizados y fijos en $90^\circ$, acople la estructura de pata (fémur y tibia fijos a $90^\circ$ vertical) de modo que queden alineadas a escuadra (apuntando verticalmente hacia abajo en perpendicular con el chasis). Fije los horns centrales con tornillos.
4.  **Montaje Superior:** Instale los pilares distanciadores M3 de 25mm, coloque las baterías en los portabaterías inferiores y fije la **Placa Base Superior** asegurando la protoboard, el ESP32, el HC-SR04 y la IMU en el puente superior.

---

## 6. Estructura del Firmware y Mapa de Archivos

La arquitectura en MicroPython asíncrono se optimiza para controlar los 4 actuadores:
*   `main.py`: Administra el bucle asíncrono, la lectura de sensores y el control de las 4 caderas.
*   `prueba_servos.py`: Diagnóstico de barrido rápido y modo armado para los 4 canales directos.
*   `prueba_servo_individual.py`: Terminal interactiva para depuración manual servo a servo.
*   `prueba_mpu6050.py`: Validador de bus I2C y telemetría inercial cruda del GY-521.
*   `classifier_ia.py`: Motor de clasificación inercial de Edge AI (NORMAL, FALLEN, PUSHED, SLIPPING).
*   `web_server.py`: Servidor HTTP no bloqueante que enruta las peticiones de control API y telemetría.
*   `dashboard.html`: Panel web premium auto-adaptable a la telemetría en tiempo real del robot.

---

## 7. Algoritmo de Locomoción y Marcha de Gateo

Con una configuración de 4 caderas oscilantes, la marcha se simplifica a un ciclo de gateo en **5 fases**:

```text
[Inicio: Pose Reposo 90°] ➔ [1. Adelantar FR] ➔ [2. Adelantar RR] 
                            ➔ [3. Adelantar FL] ➔ [4. Adelantar RL] ➔ [5. Empuje Cuerpo]
```

### Rangos de Oscilación por Espejo:
*   **Coxa Adelantado (Avanzar):** Derecha (FR/RR) = $110^\circ$ | Izquierda (FL/RL) = $75^\circ$.
*   **Coxa Atrasado (Empujar):** Derecha (FR/RR) = $70^\circ$ | Izquierda (FL/RL) = $105^\circ$.
*   **Empuje General (Fase 5):** Con todas las patas apoyadas, las caderas oscilan coordinadamente hacia atrás para desplazar físicamente el cuerpo del robot hacia adelante.

---

## 8. Inteligencia Artificial Sensorial (IA Local)

El clasificador local (`classifier_ia.py`) funciona independientemente del número de actuadores:
1.  **Detección de Caída (`FALLEN`):** Si la inclinación del Pitch/Roll supera los $\pm 45^\circ$, ante caída libre ($|a| < 0.2g$) o choque ($|a| > 2g$), el lazo de locomoción detiene la marcha asíncrona, lleva las 4 caderas a $90^\circ$ y activa la alarma intermitente del buzzer.
2.  **Estabilización Activa:** Dado que los servos Coxa solo actúan en el plano de avance/retroceso y no permiten modificar la altura vertical del pie, la compensación inercial activa diferencial se encuentra desactivada en software para esta variante de 4-DoF.

---

## 9. Protocolo de Puesta en Marcha y Calibración
1.  **Alineación Mecánica:** Coloque las patas de forma que en pose neutra ($90^\circ$ en `prueba_servos.py`) el robot se sostenga erguido.
2.  **Calibración Inercial:** Coloque el robot estable en superficie nivelada y ejecute `calibrate_mpu.py` en Thonny para generar el archivo `mpu_offsets.txt`.
3.  **Depuración Inalámbrica:** Desconecte el USB, encienda las baterías y controle el robot desde la red Wi-Fi `USS_SpiderBot_AP` ingresando a `http://192.168.4.1/`.

---

## 10. Guía de Diagnóstico y Resolución de Problemas (FAQ)

### P1: El robot no avanza y solo resbala en el suelo
*   **Causa:** Poca adherencia en las puntas de las patas, o el ángulo de empuje es muy amplio provocando pérdida de tracción.
*   **Solución:** Agregue gomas antideslizantes (o silicona caliente) en la base de contacto de las tibias y reduzca la velocidad de oscilación en `main.py` suavizando las transiciones.

### P2: El buzzer pita continuamente y el robot se bloquea al encender con baterías
*   **Causa:** La IMU GY-521 está mal cableada (no se detecta I2C en `0x68`) o el sensor clasifica falsos positivos de caída.
*   **Solución:** Ejecute `prueba_mpu6050.py` para validar la telemetría inercial y revise los cables de SDA (21) y SCL (22).

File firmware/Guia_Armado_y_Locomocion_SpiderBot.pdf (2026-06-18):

## Guía de Armado Electrónico y Sistema de Locomoción — USS SpiderBot

Solemne 3 — Taller de Programación I (Universidad San Sebastián)

Este documento contiene las especificaciones detalladas para el armado de la electrónica del robot cuadrúpedo USS SpiderBot, el diseño lógico de su sistema de locomoción (marcha de gateo) y las instrucciones para realizar pruebas de simulación y calibración inercial.

### 1. Arquitectura del Sistema y Lista de Materiales (BOM)

El USS SpiderBot es un robot caminador cuadrúpedo de 8 grados de libertad (8-DoF) diseñado para el reconocimiento de zonas de desastre (escombros). Cuenta con autonomía inercial para auto-nivelarse en terrenos rugosos y evasión reactiva ante obstáculos frontales.

Lista de Componentes Electrónicos

- 1x Microcontrolador ESP32 DevKit V1 (38 pines): Cerebro del robot que ejecuta el bucle de control en MicroPython.
- 1x Driver PWM PCA9685 (16 canales I2C): Módulo encargado de generar las señales de pulso para controlar los 8 servos, liberando pines del ESP32 y garantizando estabilidad temporal.
- 8x Servomotores SG90 o MG90S: Actuadores para el movimiento de las articulaciones (2 por pata: Coxa y Fémur).
- 1x Unidad de Medida Inercial (IMU) GY-521 (MPU6050): Acelerómetro y giroscopio de 6 ejes que mide la inclinación (Pitch y Roll) para la auto-estabilización.
- 1x Sensor de Distancia Ultrasónico HC-SR04: Sensor de prevención para detener la marcha si hay obstáculos a menos de 15 cm.
- 1x Buzzer Activo (5V): Actuador acústico para emitir pitidos de encendido, alertas de colisión inminente y alarmas de inestabilidad extrema.
- 1x Batería Li-ion 2S (7.4V nominal) + Regulador de Voltaje Step-Down (UBEC 5V/3A): Fuente de energía de alta capacidad y regulador de voltaje para aislar la potencia de los servos.

### 2. Guía de Alimentación y Conexiones (Pinout)

IMPORTANTE: El Aislamiento de Potencia

Los servomotores SG90/MG90S pueden consumir picos de corriente superiores a 500 mA cada uno cuando realizan esfuerzo mecánico (por ejemplo, al levantar el peso del robot). * Regla de Oro: NUNCA alimente los servos desde las

1

salidas de 3.3V o 5V del microcontrolador ESP32. Hacerlo causará caídas de tensión (brownouts) que reiniciarán constantemente el procesador. * Solución: Los servomotores deben conectarse directamente a la bornera de alimentación externa del módulo PCA9685 (marcada como V+ y GND), la cual se alimenta a través de la salida de 5V del regulador UBEC de 3A conectado a la batería. * GND Común: Conecte el terminal GND del ESP32, el terminal GND del bus de señal del PCA9685 y el terminal GND de la bornera de alimentación externa del regulador en un punto común para establecer una referencia de voltaje unificada.

Tabla de Conexiones del ESP32

El bus de comunicación I2C es compartido por el driver PCA9685 y la IMU MPU6050, optimizando el uso de pines en el microcontrolador.

Componente

Pin en

Componente | Pin en ESP32 | Tipo de
| | Señal Propósito /
| | Función
MPU6050
(IMU)
VCC / GND | 3.3V / GND | Alimentación Energía
| | para el
| | procesado
| | digital
| | inercial
MPU6050
(IMU)
SDA / SCL | GPIO 21 /
| GPIO 22 | I2C (Com-
| | partido) Lectura de
| | inclinación
| | angular en
| | grados
PCA9685
(Driver)
VCC / GND | 3.3V / GND | Alimentación
| | (Lógica) Energía
| | para el
| | procesador
| | interno I2C
PCA9685
(Driver)
SDA / SCL | GPIO 21 /
| GPIO 22 | I2C (Com-
| | partido) Comandos
| | de posición
| | angular
| | para servos
PCA9685
(Driver)
V+ (Bornera) | Salida 5V
| (UBEC) | Alimentación
| | (Potencia) Alimentación
| | dedicada
| | para los 8
| | servos
HC-SR04
(Sonar)
VCC / GND | 5V / GND | Alimentación El
| | transductor
| | de
| | ultrasonido
| | requiere 5V

2

Componente

Pin en
Componente Pin en ESP32

Tipo de
Señal

Propósito /
Función
HC-SR04
(Sonar)

TRIG / ECHO GPIO 18 /
GPIO 19

Digital I/O Control de
emisión y
lectura de
eco del
sonar
Buzzer
Activo

Terminal + / - GPIO 14 /
GND

Digital
OUT

Activación y
modulación
de tonos de
alerta

### 3. Esquema de Cableado Detallado

A continuación se muestra el conexionado esquemático en formato de texto. El bus I2C (GPIO 21 y GPIO 22) se deriva en paralelo hacia ambos dispositivos esclavos (PCA9685 y MPU6050).

+---------------------------+
| | | | BATERIA 2S 7.4V | |
+-------------+-------------+
| | | | (+7.4V) v

+---------------------------+
| | REGULADOR UBEC 5V/3A | |
+------+-------------+------+
(5V Potencia) | | | (5V Control/Logica)
v | v
+------------------------------+ | +------------------------------+
| | PCA9685 - Bornera V+ | | | | | ESP32 - Vin | |
| | PCA9685 - Bornera GND ---+-------+---> | ESP32 - GND | |
+------------------------------+ | +--------------+---------------+
| (3.3V Regulado)
| | | | v
+------------------------------+
| | | | | MPU6050 (IMU) - VCC | |
| | MPU6050 (IMU) - GND --->GND|
+------------------------------+

CONEXION DE SENALES (I2C y GPIOs): ==================================
ESP32 GPIO 21 (SDA) <---------+--------> PCA9685 SDA

3

+--------> MPU6050 SDA

ESP32 GPIO 22 (SCL) <---------+--------> PCA9685 SCL +--------> MPU6050 SCL

ESP32 GPIO 18 (TRIG) <----------------> HC-SR04 TRIG
ESP32 GPIO 19 (ECHO) <----------------> HC-SR04 ECHO
ESP32 GPIO 14 (SIG) <----------------> Buzzer (+) [Buzzer (-) a GND]

Configuración de Canales de Servomotores (PCA9685)

El robot se divide en 4 patas numeradas de la 0 a la 3, en una configuración cinemática Pitch-Pitch (2 ejes horizontales paralelos por pata). Esto significa que ambos servos operan en el plano vertical: el de cadera (Coxa / Hip Pitch) realiza la flexión de la cadera y el de rodilla (Fémur / Knee Pitch) la de la rodilla, prescindiendo del giro horizontal para mayor torque y estabilidad de carga:

- Pata 0 (Delantera Derecha - FR): Coxa (Hip Pitch) → Canal 0 | Fémur (Knee Pitch) → Canal 1
- Pata 1 (Delantera Izquierda - FL): Coxa (Hip Pitch) → Canal 2 | Fémur (Knee Pitch) → Canal 3
- Pata 2 (Trasera Izquierda - RL): Coxa (Hip Pitch) → Canal 4 | Fémur (Knee Pitch) → Canal 5
- Pata 3 (Trasera Derecha - RR): Coxa (Hip Pitch) → Canal 6 | Fémur
(Knee Pitch) → Canal 7

### 4. Guía de Ensamblaje Mecánico con Piezas 3D

El correcto ensamblaje de las piezas estructurales impresas en 3D con los componentes electrónicos es crucial para evitar rozamientos, esfuerzos innecesarios en los servos y desgaste de material.

### 4.1 Preparación de las Piezas Impresas

- Limpieza de Cavidades: Retire con cuidado todo el material de soporte de las cavidades destinadas a los servomotores en la placa_base_inferior y los fémures (eslabon_femur). Las tolerancias son estrechas (0.3mm total) para un ajuste a presión firme (snug fit).
- Acondicionamiento de Agujeros: Los agujeros para los tornillos M2 de fijación de bridas de servo están diseñados con un diámetro de 2.0mm. Se recomienda roscar previamente los orificios metiendo y sacando un tornillo de prueba para facilitar el ensamblaje final.

4

### 4.2 Secuencia de Montaje Mecánico Paso a Paso

graph TD
Step1[1. Limpieza de piezas 3D y preparación de orificios] --> Step2[2. Insertar y atornillar 4 Servos de Cadera en Placa Inferior] Step2 --> Step3[3. Insertar y atornillar 4 Servos de Rodilla en Fémures]
Step3 --> Step4[4. Calibración del Cero Eléctrico de todos los servos]
Step4 --> Step5[5. Acoplar y atornillar Fémures a los Horns de Cadera]
Step5 --> Step6[6. Acoplar y atornillar Tibias a los Horns de Rodilla] Step6 --> Step7[7. Montaje de Pilares, Placa Superior y Sensores]
1. Paso 1: Montaje de Servos de Cadera (Hip Pitch)
- Tome la Placa Base Inferior e inserte a presión cada uno de
los 4 servos de cadera en sus respectivos soportes perimetrales (soporte_servo_cadera).
- Orientación: El eje de salida estriado de cada servo debe quedar posicionado hacia el lado del rebaje frontal del soporte (X = 5.5).
- Asegure los servos utilizando tornillos autorroscantes M2 (dos por servo) atravesando las bridas del servo hacia la base de plástico.
- Rutee los cables de señal hacia el interior del chasis a través de las canaletas internas.
2. Paso 2: Montaje de Servos de Rodilla (Knee Pitch)
- Tome los 4 fémures (eslabon_femur) e inserte a presión un servo en el bolsillo de rodilla de cada fémur.
- Orientación: El eje estriado de salida debe quedar alineado con el extremo exterior del fémur (X = 55.0).
- Asegure el servo al fémur con dos tornillos autorroscantes M2.
- Pase el cable del servo a lo largo de la ranura lateral del fémur hacia la articulación de la cadera.
3. Paso 3: Calibración del Cero Eléctrico (CRÍTICO)
- Antes de acoplar los fémures y tibias, conecte el ESP32 y el PCA9685 y enciéndalos.
- Cargue el firmware main.py para forzar a todos los servos a la posición de reposo estática (pos_reposo()): caderas a 90∘ y rodillas a 60∘/120∘
- Nota: Nunca intente ensamblar los brazos de plástico (horns) con los servos apagados o desalineados.
4. Paso 4: Acoplamiento del Fémur a la Cadera
- Con los servos energizados en reposo (90∘
), tome el fémur y encaje
su acoplamiento de horn en el eje del servo de cadera.
- Alineación: El fémur debe quedar alineado a escuadra vertical (apuntando a 90∘ perpendicular respecto al plano de la base).
- Fije el fémur introduciendo el tornillo central del servo y dos tornillos pequeños de fijación en los orificios del horn.
5. Paso 5: Acoplamiento de la Tibia a la Rodilla
- Con los servos energizados en reposo (60∘ para pata derecha, 120∘ para pata izquierda), tome la tibia (tibia_inferior) y encaje su

5

acoplamiento de horn en el eje del servo de rodilla.
- Alineación: La tibia debe quedar apuntando hacia abajo, formando una pose estable.
- Fije la tibia usando el tornillo central del servo y tornillos pequeños de fijación.
6. Paso 6: Montaje del Doble Deck y Componentes Superiores
- Fije los 4 pilares espaciadores M3 de 22mm en los orificios de la Placa Base Inferior.
- Posicione el driver PCA9685 en la placa inferior y rutee todos los cables. Conecte los 8 servos a sus respectivos canales (0-7).
- Coloque la Placa Base Superior sobre los pilares y asegúrela con tornillos M3.
- Fije el ESP32 DevKit V1 en los soportes superiores de la tapa.
- Monte la IMU MPU6050 y el sensor ultrasónico HC-SR04 y realice el conexionado de señales con jumpers según el pinout de la sección 2.

### 5. Algoritmo de Locomoción: Marcha de Gateo (Crawl Gait)

Cinemática del Movimiento Cuadrúpedo

Para que el robot camine manteniendo estabilidad estática, debe cumplir la regla física del Polígono de Sustentación. En cualquier instante en que se levante una pata, las otras tres deben estar firmemente apoyadas en el suelo formando un triángulo de soporte que encierre la proyección vertical del centro de masa (CoM) del chasis.

El ciclo de la marcha de gateo consta de 5 fases secuenciales:

graph TD
A[Bucle de Caminata] --> B[Fase 1: Empuje General del Cuerpo - Stance Shift] B --> C[Fase 2: Paso Pata Delantera Derecha - FR]
C --> D[Fase 3: Paso Pata Trasera Derecha - RR]
D --> E[Fase 4: Paso Pata Delantera Izquierda - FL]
E --> F[Fase 5: Paso Pata Trasera Izquierda - RL] F --> A

Definición de Ángulos del Ciclo

Para mover una articulación de forma simétrica a la derecha e izquierda, debemos tomar en cuenta la inversión mecánica de los servos en espejo en el chasis: * Fémur en Reposo (Apoyo): Derecha = 60∘

| Izquierda = 120∘
* Fémur Levantado (Swing): Ambas patas van a 90∘
(posición media que
levanta el pie del suelo). * Coxa Adelantado (FWD): Derecha = 110∘ |

6

Izquierda = 75∘

. * Coxa Atrasado (BWD): Derecha = 70∘ | Izquierda =
105∘

El Ciclo Paso a Paso:
1. Fase de Empuje (Stance Shift): Con las 4 patas en apoyo (60∘/120∘ ),
todos los servos Coxa se mueven simultáneamente hacia atrás (Coxa BWD). Esto desplaza el cuerpo del robot hacia adelante.
2. Paso Pata 0 (FR): Levanta el fémur a 90∘

, gira su Coxa a FWD (110∘ ),
y vuelve a bajar el fémur a su ángulo de apoyo (60∘ ).
3. Paso Pata 3 (RR): Levanta el fémur a 90∘

, gira su Coxa a FWD (110∘ ),
y vuelve a bajar el fémur a su ángulo de apoyo (60∘ ).
4. Paso Pata 1 (FL): Levanta el fémur a 90∘

, gira su Coxa a FWD (75∘
),
y vuelve a bajar el fémur a su ángulo de apoyo (120∘ ).
5. Paso Pata 2 (RL): Levanta el fémur a 90∘

, gira su Coxa a FWD (75∘
),
y vuelve a bajar el fémur a su ángulo de apoyo (120∘
).

### 6. Control y Lazo de Compensación Inercial Activa

El control reactivo del robot opera de manera simultánea en el firmware. En cada subdivisión del movimiento: 1. Se lee la inclinación en Pitch y Roll desde el acelerómetro MPU6050. 2. Si la inclinación supera la tolerancia (±3∘
), se
calcula un factor de compensación diferencial que se aplica a los ángulos objetivo de los fémures apoyados:

Ángulo Compensado = Ángulo Base ± (Inclinación × Factor de Compensación)

3. Esta corrección angular levanta las patas del lado inclinado hacia abajo y baja las del lado inclinado hacia arriba, logrando una auto-nivelación en tiempo real.
4. Las patas en fase de oscilación (levantadas a 90∘
en swing) se excluyen de la compensación para que su movimiento de avance no interfiera mecánicamente.

### 7. Procedimiento de Pruebas y Puesta en Marcha

Para asegurar un armado exitoso y evitar daños en los componentes, ejecute la siguiente secuencia de pruebas antes de colocar el chasis impreso en 3D en el suelo:

Paso A: Calibración del Cero Mecánico

1. Conecte el ESP32 y el PCA9685 sin montar los brazos de servo (horns) de plástico a los servomotores.
2. Cargue el código firmware main.py para llevar los servos a la posición de reposo (pos_reposo()): caderas a 90∘ y muslos a 60∘/120∘

7

3. Con los servos energizados y fijos en esa posición de control, coloque mecánicamente los horns plásticos alineados a escuadra de forma manual (perpendiculares para la cadera, y en la inclinación correspondiente para el muslo). Atornille los horns. Esto garantiza que el software y la estructura física compartan la misma referencia angular de origen.

Paso B: Calibración de Offsets del Acelerómetro

1. Posicione el robot en una superficie completamente horizontal y plana de forma estable.
2. Ejecute en Thonny el script calibrate_mpu.py.
3. El programa tomará 100 muestras consecutivas, promediará los offsets de aceleración del chip y guardará estos valores en el archivo local mpu_offsets.txt. El programa principal main.py cargará este archivo al arrancar para referenciar los 0

∘
exactos.

Paso C: Simulación del Circuito en Wokwi

Antes de realizar el conexionado físico final con jumpers, puede validar de forma interactiva el circuito y su lógica en el simulador en la nube: 1. Vaya a wokwi.com y cree un nuevo proyecto de tipo ESP32 con MicroPython.
2. Sustituya el archivo de conexiones por el contenido de nuestro diagram.json. 3. Suba los controladores locales (mpu6050.py, sonar_sensor.py, buzzer_alert.py, pca9685.py) y el código main.py. 4. Inicie la simulación, ajuste la distancia del sensor ultrasónico y observe cómo el buzzer y los servos reaccionan dinámicamente.

### 8. Pasos Pendientes para la Finalización del Proyecto

Para llevar el USS SpiderBot a su culminación funcional y entrega exitosa en la Solemne 3, se debe seguir la siguiente lista de tareas críticas:

### 1. Impresión de Piezas Físicas (FDM)

- Parámetros de Laminación recomendados (Slicing):
– Altura de capa: 0.2 mm.
– Perímetros: 3 o 4 (indispensable para la resistencia de los soportes de servos y orificios M2).
– Relleno (Infill): 20% a 30% en tipo Gyroid (giroidal) para optimizar la relación peso/resistencia.
– Material: PLA de buena calidad para el cuerpo y las patas, o PETG si se requiere mayor resistencia a impactos en terrenos rugosos.
- Impresoras Disponibles: Se recomienda utilizar la Creality K1 o Ender 3 V3 KE para las placas de chasis principales por su velocidad y precisión dimensional, y la Ender 3 V3 SE para las tibias y fémures.

8

### 2. Calibración Mecánica y del Lazo de Control (Fase Física)

- Calibración Estática (cero mecánico): Comprobar que en la pose de reposo estática (pos_reposo() en main.py), los fémures y tibias queden perfectamente alineados a escuadra. Cualquier desviación física de montaje debe corregirse mediante software modificando las constantes de offset angular individuales o desatornillando el horn y volviéndolo a alinear.
- Calibración Dinámica del MPU6050: Ejecutar el calibrador inercial calibrate_mpu.py sobre una superficie plana para generar el archivo mpu_offsets.txt. Esto evitará derivas angulares y errores de auto-nivelación.

### 3. Ajuste Fino de la Marcha en Suelo (Gait Tuning)

- Monitoreo de Consumo de Corriente: Colocar el robot en el suelo y realizar pruebas de caminata monitoreando que el regulador UBEC de 3A no se sobrecaliente.
- Ajuste de Amplitud de Paso: Si el robot patina o pierde tracción en el suelo, ajustar los rangos angulares de empuje y avance en caminar_adelante() dentro de main.py. Reducir el ángulo Coxa FWD/BWD (por ejemplo, reducir el swing a 80∘ − 100∘
| en lugar de
70∘ − 110∘
) para suavizar la aceleración.
- Ajuste del Coeficiente de Estabilización: Variar la constante FACTOR_COMPENSACION en main.py si la nivelación inercial reacciona de forma muy lenta o muy brusca (con oscilaciones).

### 4. Pruebas de Integración y Casos de Fallo

- Prueba del Sensor de Obstáculos (HC-SR04): Verificar que el robot se detenga inmediatamente (marcha abortada) y emita la alarma acústica cuando el sensor ultrasónico detecte un obstáculo a menos de 15 cm.
- Prueba de Alarma Inercial: Validar que el buzzer emita una advertencia si el robot se inclina más de 15∘
en Pitch o Roll, alertando de un posible volcamiento o pérdida de apoyo.

9

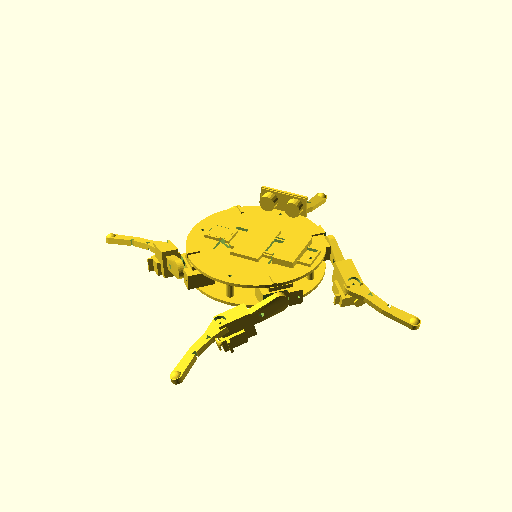
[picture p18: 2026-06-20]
cad/ensamble_render_definitivo.png

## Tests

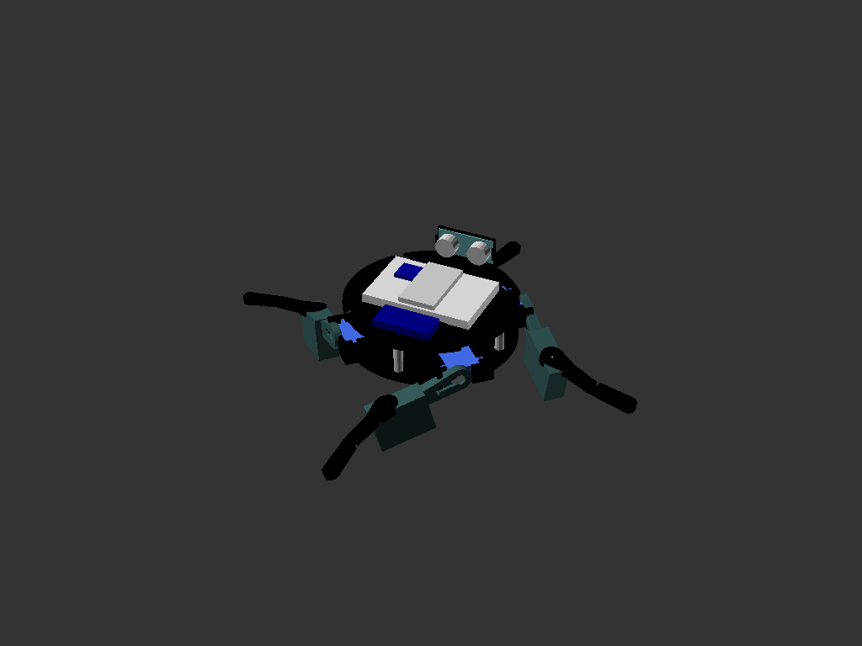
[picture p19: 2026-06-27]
cad/ensamble_render_verificado.png

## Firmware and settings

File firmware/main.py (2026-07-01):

# ============================================================
# USS SPIDERBOT — Bucle Principal y Estabilización Activa (Asíncrono)
# Solemne 3 — Taller de Programación I
# Microcontrolador: ESP32
# Lenguaje: MicroPython
# ============================================================

from machine import I2C, Pin, PWM
import time
import uasyncio as asyncio
import sys
import select
import state
from mpu6050 import MPU6050
from sonar_sensor import SonarSensor
from buzzer_alert import BuzzerAlert
from classifier_ia import IASensorClassifier

class ESP32ServoDirect:
    """
    Controlador de servos conectado directamente a pines GPIO de la ESP32.
    Los servos son alimentados a 6.0V por el LM2596 #1 (pack 18650 independiente).
    La ESP32 y los sensores se alimentan a 5.0V por el LM2596 #2.
    """
    def __init__(self, channels_pins):
        self.pwms = {}
        for ch, pin_num in channels_pins.items():
            try:
                # Frecuencia de 50Hz para servomotores analógicos estándar
                pwm = PWM(Pin(pin_num), freq=50)
                self.pwms[ch] = pwm
            except Exception as e:
                print(f"[WARNING] No se pudo iniciar PWM en GPIO {pin_num}:", e)

    def set_servo_angle(self, channel, angle):
        if channel in self.pwms:
            # 50Hz -> Período = 20ms.
            # Ciclo de trabajo típico para servos SG90 (0.5ms a 2.5ms de ancho de pulso):
            # 0.5ms / 20ms = 2.5% -> 0.025 * 65535 = 1638 ticks
            # 2.5ms / 20ms = 12.5% -> 0.125 * 65535 = 8192 ticks
            min_duty = 1638
            max_duty = 8192
            
            # Clampear ángulo entre 0 y 180
            angle = max(0, min(180, angle))
            
            duty = int(min_duty + (angle / 180.0) * (max_duty - min_duty))
            self.pwms[channel].duty_u16(duty)

# ── 1. Inicialización de Interfaces ──────────────────────────────
print("Iniciando bus I2C (SDA=21, SCL=22, Freq=100kHz) para IMU...")
i2c = I2C(0, sda=Pin(21), scl=Pin(22), freq=100000)

dispositivos = i2c.scan()
print("Dispositivos I2C detectados: ", [hex(d) for d in dispositivos])

# ── 2. Inicialización de Drivers ────────────────────────────────
# Mapeo de canales a pines GPIO físicos en la ESP32 (Control Directo 4-DoF)
channels_pins = {
    0: 23, # Pata 0 (FR) - Coxa
    1: 17, # Pata 1 (FL) - Coxa
    2: 15, # Pata 2 (RL) - Coxa
    3: 13  # Pata 3 (RR) - Coxa
}

print("Inicializando controlador de servos directo por GPIO (4 canales)...")
servos = ESP32ServoDirect(channels_pins)

# Auto-detectar si estamos corriendo en el simulador Wokwi buscando la red virtual
modo_simulacion = False
try:
    import network
    sta = network.WLAN(network.STA_IF)
    sta.active(True)
    print("Escaneando redes Wi-Fi para auto-detectar simulador...")
    redes = sta.scan()
    ssids = [r[0].decode('utf-8') for r in redes]
    if "Wokwi-GUEST" in ssids:
        print("[INFO] Red 'Wokwi-GUEST' detectada. Entorno: SIMULADOR WOKWI.")
        modo_simulacion = True
    else:
        print("[INFO] Red 'Wokwi-GUEST' no detectada. Entorno: HARDWARE REAL.")
except Exception as e:
    print("[WARNING] Falló escaneo de red para auto-detección:", e)

try:
    imu = MPU6050(i2c, address=0x68)
    print("[OK] Acelerómetro (MPU6050) configurado.")
    # Intentar cargar los offsets de calibración guardados
    try:
        with open("mpu_offsets.txt", "r") as f:
            linea = f.read().strip()
            ox, oy, oz = [int(v) for v in linea.split(",")]
            imu.set_offsets(ox, oy, oz)
            print(f"[OK] Offsets de IMU cargados: X={ox}, Y={oy}, Z={oz}")
    except OSError:
        print("[WARNING] No se encontró mpu_offsets.txt. Usando offsets por defecto (0,0,0).")
except Exception as e:
    print("[ERROR] No se pudo iniciar el MPU6050: ", e)
    imu = None

sonar = SonarSensor(trigger_pin=18, echo_pin=19)
alarma = BuzzerAlert(pin_number=14)

clasificador_ia = IASensorClassifier()

alarma.play_startup() # Melodía rítmica de inicio para buzzer activo

# ── 3. Definición de Canales de Servos y Poses (4-DoF) ──────────────
COXA_CHANNELS = [0, 1, 2, 3]

# Registro del estado actual de los ángulos de los servos para interpolaciones
estado_coxas = [90, 90, 90, 90]

def establecer_angulo_pata(indice, coxa_ang, femur_ang=90):
    """Establece los ángulos de una pata (Coxa/Cadera)."""
    if not servos: return
    
    # Límites físicos de seguridad para los servos SG90 (15° a 165°)
    coxa_ang = max(15, min(165, int(coxa_ang)))
    
    # Enviar señal PWM al servo de cadera de la pata seleccionada
    servos.set_servo_angle(COXA_CHANNELS[indice], coxa_ang)

def pos_reposo(secuencial=False):
    """Lleva a todos los servos del cuadrúpedo a su pose de reposo estático (90 grados)."""
    global estado_coxas
    if not servos: return
    
    estado_coxas = [90, 90, 90, 90]
    
    # Mover las 4 caderas a 90 grados
    for i in range(4):
        establecer_angulo_pata(i, 90)
        if secuencial:
            time.sleep_ms(250)

# Establecer pose inicial al arrancar de forma secuencial (para evitar brownouts)
pos_reposo(secuencial=True)

async def mover_suave_ciclo(coxa_targets, femur_targets=None, pasos=4, delay_ms=12):
    """Interpola los ángulos suavemente mientras monitorea obstáculos de forma asíncrona."""
    global estado_coxas
    for paso in range(1, pasos + 1):
        # Monitorear sensor ultrasónico por seguridad
        if 0.0 < state.distancia_actual < 15.0:
            return False  # Abortar movimiento inmediatamente por obstáculo
            
        t = paso / pasos
        for i in range(4):
            c_ang = estado_coxas[i] + (coxa_targets[i] - estado_coxas[i]) * t
            establecer_angulo_pata(i, c_ang)
        await asyncio.sleep_ms(delay_ms)
        
    estado_coxas = list(coxa_targets)
    return True

# ── 5. Definición de Marchas de Locomoción Asíncronas ──────────────

async def caminar_adelante():
    """Ejecuta un ciclo de marcha de gateo para 4 caderas hacia adelante."""
    # Paso 1: Adelantar Pata FR (Delantera Derecha)
    if not await mover_suave_ciclo([110, 90, 90, 90], None, pasos=3): return False
    # Paso 2: Adelantar Pata RR (Trasera Derecha)
    if not await mover_suave_ciclo([110, 90, 90, 110], None, pasos=3): return False
    # Paso 3: Adelantar Pata FL (Delantera Izquierda)
    if not await mover_suave_ciclo([90, 70, 90, 110], None, pasos=3): return False
    # Paso 4: Adelantar Pata RL (Trasera Izquierda)
    if not await mover_suave_ciclo([90, 70, 70, 90], None, pasos=3): return False
    # Paso 5: Empuje del cuerpo hacia adelante (todos los apoyos retroceden)
    if not await mover_suave_ciclo([70, 110, 110, 70], None, pasos=4): return False
    return True

async def caminar_atras():
    """Ejecuta un ciclo de marcha de gateo para 4 caderas hacia atrás."""
    # Paso 1: Retroceder Pata FR
    if not await mover_suave_ciclo([70, 90, 90, 90], None, pasos=3): return False
    # Paso 2: Retroceder Pata RR
    if not await mover_suave_ciclo([70, 90, 90, 70], None, pasos=3): return False
    # Paso 3: Retroceder Pata FL
    if not await mover_suave_ciclo([90, 110, 90, 70], None, pasos=3): return False
    # Paso 4: Retroceder Pata RL
    if not await mover_suave_ciclo([90, 110, 110, 90], None, pasos=3): return False
    # Paso 5: Empuje del cuerpo hacia atrás (todos los apoyos avanzan)
    if not await mover_suave_ciclo([110, 70, 70, 110], None, pasos=4): return False
    return True

async def girar_izquierda():
    """Ejecuta rotación sobre su propio eje en sentido antihorario."""
    if not await mover_suave_ciclo([110, 110, 70, 70], None, pasos=4): return False
    if not await mover_suave_ciclo([70, 70, 110, 110], None, pasos=4): return False
    return True

async def girar_derecha():
    """Ejecuta rotación sobre su propio eje en sentido horario."""
    if not await mover_suave_ciclo([70, 70, 110, 110], None, pasos=4): return False
    if not await mover_suave_ciclo([110, 110, 70, 70], None, pasos=4): return False
    return True

# ── 6. Tareas Coactivas Asíncronas (Tasks) ─────────────────────────

async def sensor_updater():
    """Actualiza continuamente los valores de telemetría de sensores a 20Hz."""
    print("Iniciando tarea de monitoreo de sensores (20Hz)...")
    loop_count = 0
    sonar_fail_count = 0
    while True:
        # 1. Medir distancia ultrasónica
        # Si el sonar falla de forma consecutiva, reducimos el muestreo a 0.5Hz para evitar bloquear la CPU con timeouts
        if sonar_fail_count < 5 or loop_count % 40 == 0:
            dist = sonar.medir_distancia()
            if dist < 0:
                sonar_fail_count += 1
            else:
                sonar_fail_count = 0
            state.distancia_actual = dist
        else:
            # Mantener telemetría en error pero evitar la llamada bloqueante
            state.distancia_actual = -1.0
        
        # 2. Medir inclinación MPU6050 y clasificar estado IA
        if imu:
            try:
                ax, ay, az = imu.read_accel_calibrated()
                gx, gy, gz = imu.read_gyro_raw()
                state.pitch_actual, state.roll_actual = imu.obtener_inclinacion()
                state.estado_ia = clasificador_ia.classify(ax, ay, az, gx, gy, gz, state.comando_actual)
                
                # Alerta inercial si el robot se inclina peligrosamente (>15 grados)
                if abs(state.pitch_actual) > 15.0 or abs(state.roll_actual) > 15.0:
                    alarma.alerta_postura()
            except Exception as e:
                pass # Silenciar fallas momentáneas de lectura I2C
                
        # Imprimir telemetría en consola una vez cada 2 segundos (40 ciclos)
        loop_count = (loop_count + 1) % 40
        if loop_count == 0:
            print(f"[IMU] Pitch: {state.pitch_actual:.1f}°, Roll: {state.roll_actual:.1f}° | [Sonar]: {state.distancia_actual:.1f} cm | Cmd: {state.comando_actual}")
            
        await asyncio.sleep_ms(50)

async def locomotion_loop():
    """Supervisa y procesa el estado actual del comando de movimiento."""
    print("Iniciando tarea de control de locomoción...")
    while True:
        # A. Detección de caída por IA sensorial
        if state.estado_ia == "FALLEN":
            print("[ALERTA IA] ¡Caída detectada! Deteniendo y emitiendo alarma.")
            alarma.alerta_postura()
            pos_reposo()
            state.comando_actual = "stop"
            await asyncio.sleep_ms(500)
            continue

        # B. Prevención de colisión inmediata reactiva local
        if 0.0 < state.distancia_actual < 15.0:
            print("[ALERTA] Obstáculo crítico! Deteniendo cuadrúpedo de inmediato.")
            alarma.play_critical_alert() # Alerta crítica rítmica
            pos_reposo()
            state.comando_actual = "stop"
            await asyncio.sleep_ms(1000)
            continue
            
        # B. Selección de marcha según estado
        cmd = state.comando_actual
        if cmd == "forward":
            marchando = await caminar_adelante()
            if not marchando:
                print("[ALERTA] Marcha adelante cancelada por obstáculo.")
                alarma.play_warning_alert() # Alerta de advertencia corta
                pos_reposo()
                state.comando_actual = "stop"
                await asyncio.sleep_ms(500)
        elif cmd == "backward":
            marchando = await caminar_atras()
            if not marchando:
                print("[ALERTA] Marcha atrás cancelada por obstáculo.")
                alarma.play_warning_alert() # Alerta de advertencia corta
                pos_reposo()
                state.comando_actual = "stop"
                await asyncio.sleep_ms(500)
        elif cmd == "left":
            marchando = await girar_izquierda()
            if not marchando:
                pos_reposo()
                state.comando_actual = "stop"
                await asyncio.sleep_ms(500)
        elif cmd == "right":
            marchando = await girar_derecha()
            if not marchando:
                pos_reposo()
                state.comando_actual = "stop"
                await asyncio.sleep_ms(500)
        elif cmd == "reposo":
            pos_reposo()
            while state.comando_actual == "reposo":
                await asyncio.sleep_ms(100)
        else:
            # Comando "stop" o apagado: aplicar pose de reposo y esperar a que cambie el comando
            pos_reposo()
            while state.comando_actual in ("stop", ""):
                await asyncio.sleep_ms(100)

async def serial_listener():
    """Escucha comandos de consola serie (Thonny/Wokwi) de forma no bloqueante."""
    # Esperar un momento a que las otras tareas inicien e impriman sus mensajes
    await asyncio.sleep_ms(1000)
    print("\n====================================================================")
    print("[SERIAL] Consola serie activa para control directo de simulación.")
    print("         Escribe: 'forward', 'backward', 'left', 'right', 'stop'")
    print("                  'reposo' o 'stabilize' y pulsa Enter.")
    print("====================================================================\n")
    
    spoll = select.poll()
    spoll.register(sys.stdin, select.POLLIN)
    
    while True:
        if spoll.poll(0):
            line = sys.stdin.readline().strip().lower()
            if line in ["forward", "backward", "left", "right", "stop", "reposo"]:
                state.comando_actual = line
                print(f"[CONSOLA] Comando cambiado a: {line}")
                alarma.play_warning_alert() # Beep corto de confirmación
            elif line == "stabilize":
                state.estabilizacion_activa = not state.estabilizacion_activa
                print(f"[CONSOLA] Estabilización activa set a: {state.estabilizacion_activa}")
                alarma.play_warning_alert() # Beep corto de confirmación
            else:
                print(f"[CONSOLA] Comando desconocido: '{line}'")
        await asyncio.sleep_ms(100)

async def main_async():
    """Punto de entrada principal para orquestar la concurrencia."""
    from web_server import iniciar_wifi, start_server_task
    
    # Configuración de Wi-Fi adaptativa
    if modo_simulacion:
        print("[INFO] Simulación detectada. Conectando a red virtual Wokwi (SSID: Wokwi-GUEST)...")
        ip = iniciar_wifi(ssid="Wokwi-GUEST", password=None, modo_ap=False)
    else:
        ip = iniciar_wifi(ssid="USS_SpiderBot_AP", modo_ap=True)
    
    # Crear tareas concurrentes en el event loop
    task_sensors = asyncio.create_task(sensor_updater())
    task_locomotion = asyncio.create_task(locomotion_loop())
    task_server = asyncio.create_task(start_server_task(ip))
    task_serial = asyncio.create_task(serial_listener())
    
    print("\n[OK] USS SpiderBot completamente operativo e interactivo.")
    
    # Unir tareas para ejecución indeterminada
    await asyncio.gather(task_sensors, task_locomotion, task_server, task_serial)

# ── 7. Ejecución del Bucle de Eventos ──────────────────────────────
try:
    asyncio.run(main_async())
except AttributeError:
    # Compatibilidad con motores antiguos de MicroPython
    loop = asyncio.get_event_loop()
    loop.run_until_complete(main_async())
except KeyboardInterrupt:
    print("\n[INFO] Ejecución detenida por teclado por el operador.")
finally:
    print("Apagando motores y liberando puertos...")
    # Intento de llevar a reposo (puede fallar si no hay PWM ya activo)
    try:
        pos_reposo()
    except:
        pass
    try:
        alarma.play_shutdown() # Melodía rítmica de apagado para buzzer activo
    except:
        pass
    alarma.apagar()

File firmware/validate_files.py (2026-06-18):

#!/usr/bin/env python3
# ============================================================
# USS SPIDERBOT — Validador de Sintaxis de Archivos Python
# Solemne 3 — Taller de Programación I
# Python 3 — Ejecución Local
# ============================================================
# Escanea automáticamente todos los archivos .py en la carpeta
# USS_SpiderBot/ y verifica que compilen correctamente usando
# el módulo nativo ast. Genera un reporte en consola.
# ============================================================

import ast
import sys
import os

SCRIPT_DIR = os.path.dirname(os.path.abspath(__file__))

def validar_archivo(ruta):
    with open(ruta, "r", encoding="utf-8") as f:
        source = f.read()
    try:
        ast.parse(source, filename=ruta)
        return True, None
    except SyntaxError as e:
        return False, str(e)

def main():
    archivos_py = sorted([
        f for f in os.listdir(SCRIPT_DIR)
        if f.endswith(".py") and os.path.isfile(os.path.join(SCRIPT_DIR, f))
    ])

    if not archivos_py:
        print("No se encontraron archivos .py en el directorio.")
        sys.exit(0)

    print("=" * 60)
    print("  Validador de Sintaxis — USS SpiderBot")
    print("=" * 60)

    errores = 0

    for archivo in archivos_py:
        ruta = os.path.join(SCRIPT_DIR, archivo)
        ok, error_msg = validar_archivo(ruta)
        if ok:
            print(f"  [OK] {archivo}")
        else:
            print(f"  [ERROR] {archivo}: {error_msg}")
            errores += 1

    print("=" * 60)
    total = len(archivos_py)
    print(f"  Resumen: {total - errores}/{total} archivos OK", end="")
    if errores > 0:
        print(f", {errores} archivo(s) con error(es)")
    else:
        print()
    print("=" * 60)

    return 1 if errores > 0 else 0

if __name__ == "__main__":
    sys.exit(main())

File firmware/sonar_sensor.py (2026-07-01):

from machine import Pin
import time

class SonarSensor:
    """Clase para medir distancia usando sensor de ultrasonido HC-SR04."""
    
    def __init__(self, trigger_pin=18, echo_pin=19):
        self.trigger = Pin(trigger_pin, Pin.OUT)
        self.echo = Pin(echo_pin, Pin.IN)
        self.trigger.value(0)
        time.sleep_ms(20) # Estabilizar
        
    def medir_distancia(self) -> float:
        """Envía pulso y retorna la distancia medida en cm. Retorna -1.0 en caso de error."""
        # 1. Asegurar trigger en bajo
        self.trigger.value(0)
        time.sleep_us(2)
        
        # 2. Pulso de 10us
        self.trigger.value(1)
        time.sleep_us(10)
        self.trigger.value(0)
        
        # 3. Esperar inicio de pulso (ECHO = 1)
        timeout_start = time.ticks_us()
        while self.echo.value() == 0:
            if time.ticks_diff(time.ticks_us(), timeout_start) > 5000: # 5ms timeout (suficiente para ~85cm)
                return -1.0
                
        t_start = time.ticks_us()
        
        # 4. Esperar fin de pulso (ECHO = 0)
        timeout_end = time.ticks_us()
        while self.echo.value() == 1:
            if time.ticks_diff(time.ticks_us(), timeout_end) > 5000: # 5ms timeout
                return -1.0
                
        t_end = time.ticks_us()
        
        # 5. Calcular distancia
        duracion = time.ticks_diff(t_end, t_start)
        distancia = (duracion * 0.0343) / 2
        
        if 2.0 <= distancia <= 400.0:
            return round(distancia, 1)
        else:
            return -1.0

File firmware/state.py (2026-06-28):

# ============================================================
# USS SPIDERBOT — Registro de Estado Global Compartido
# Solemne 3 — Taller de Programación I
# ============================================================
# Este archivo centraliza el estado en tiempo real del robot,
# permitiendo la comunicación bidireccional asíncrona entre
# el bucle de locomoción (main.py) y el servidor web (web_server.py)
# sin incurrir en problemas de importación circular en MicroPython.
# ============================================================

# Comando de movimiento actual ("forward", "backward", "left", "right", "stop", "reposo")
comando_actual = "stop"

# Interruptor de la compensación inercial por acelerómetro
estabilizacion_activa = True

# Variables físicas medidas por los sensores actualizadas a 20Hz
pitch_actual = 0.0
roll_actual = 0.0
distancia_actual = 100.0

# Estado clasificado por la IA sensorial embebida
estado_ia = "NORMAL"

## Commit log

2026-06-18 feat: upload firmware, 3D CAD files and CodeWiki docs
    [chasis_orugas.scad, cuerpo_cuadruepdo.scad, cuerpo_cuadruepdo.stl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]
2026-06-19 feat: complete Wokwi simulation with 8 direct servos and I2C fallback driver
2026-06-19 Fix: Corrección de pines de alimentación de servos en diagram.json y sincronización de firmware
    [main.py]
2026-06-20 TAREA-OC-20: Synced rediseno mecanico from Diseño 3D
    - Tolerancias FDM en soportes servo y cavidades
    - Cunas de montaje para ESP32, MPU6050, XL6009E1, HC-SR04
    - Horn lock slots single-arm en femur y tibia
    [cuerpo_cuadruepdo.scad, cuerpo_cuadruepdo.stl, ensamble_cuadruepodo.scad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]
2026-06-20 design: mechanical redesign phase 2 - enlarge base plate servo slots, fix femur horn lock, add 400-point breadboard cradle
    [cuerpo_cuadruepdo.scad, cuerpo_cuadruepdo.stl, ensamble_cuadruepodo.scad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]
2026-06-20 design: mechanical redesign phase 2 - restore hip block length, fix dual-depth pockets to prevent floating screw holes
    [cuerpo_cuadruepdo.scad, cuerpo_cuadruepdo.stl, eslabon_femur.stl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]
2026-06-20 chore: remove legacy tracked robot and thermal camera CAD files
    [chasis_orugas.scad, cuerpo_cuadruepdo.scad, eslabon_oruga.scad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]
2026-06-20 feat: add hybrid SP-8 inspired leg design (TAREA-OC-23)
    [cuerpo_cuadruepdo_hibrido.scad, ensamble_cuadruepodo_hibrido.scad, eslabon_pata_hibrido.scad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]
2026-06-21 fix: align leg positioning radial translation to cuerpo_r - 7 in ensamble
    [ensamble_cuadruepodo.scad]
2026-06-21 doc: add 3D printing guide for Creality Print
2026-06-21 feat: add Creality Print 3D print project file (spiderbot.3mf)
    [spiderbot.3mf]
2026-06-22 docs: agregar informe tecnico final y presentacion beamer del hall
2026-06-23 docs: corregir errores de compilacion y actualizar evidencias visuales en informe y presentacion
2026-06-23 docs: integrar capturas de openscad, corregir desbordes de tablas con tabularx y formato markdown en informe y diapositivas
2026-06-23 feat: enlarge protoboard and regulador slots, add servo wire routing holes, and add prueba_servos test script
    [cuerpo_cuadruepdo.scad, cuerpo_cuadruepdo_hibrido.scad, placa_base_inferior.stl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]
2026-06-24 docs: update deliverables to July 1st, 2026, remove PCA9685 references, and detail 2S 14500 batteries and UBEC step-down regulator
    [cuerpo_cuadruepdo.scad, cuerpo_cuadruepdo_hibrido.scad, ensamble_cuadruepodo.scad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]
2026-06-24 design: open up servo pockets in hip brackets and femur knee block for physical assembly
    [cuerpo_cuadruepdo.scad, eslabon_femur.stl, eslabon_pata_cuadrupedo.scad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]
2026-06-24 firmware: update test scripts for ESP32 direct GPIO and add firmware usage guide
2026-06-24 firmware: configure active buzzer for rhythmic melodies and update main application
    [buzzer_alert.py, main.py]
2026-06-27 mec: rediseño tolerancias bracket servo cadera + canal salida cable lateral
    - Ampliar slot de orejas a 3.5mm ancho x 33.5mm largo para SG90
    - Reducir cavidad inferior a 25.0mm dejando material sólido para tornillos M2
    - Reubicar agujeros M2 a Y=5.5 alineados con pestañas físicas del servo
    - Añadir ranura de deslizamiento de corona (12.4x15x7.5mm) en Z=11.25
    - Canal lateral de salida de cables (4x9x16mm) en X=13, Y=-10.5
    - Corregir rotación dummy servo en ensamble a [90,-90,180]
    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
    [cuerpo_cuadruepdo.scad, ensamble_cuadruepodo.scad, eslabon_femur.stl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]
2026-06-28 docs/firmware: actualizar diagramas y reportes para alimentacion dual regulada (18650 + LM2596)
2026-06-28 docs: agregar reporte de evaluacion de diseno 3d de nuevos componentes
2026-06-28 web/dashboard: agregar dashboard de produccion y actualizar web_server
2026-06-28 ia/embedded: integrar clasificador inercial de IA sensorial en firmware y reportes
2026-06-28 docs: corregir anchos de columna y desborde en la tabla 2 de conexiones
2026-06-28 docs/presentation: sincronizar imagenes personalizadas de OpenSCAD en informe y presentacion
2026-06-28 repo/public: agregar README de alta calidad, licencia MIT y limpiar archivos temporales
2026-06-30 docs: actualizar guia de armado definitiva y compilar ultimos entregables PDF
2026-07-01 firmware: agregar script autoportante de prueba para MPU6050 (GY-521)
2026-07-01 Actualizar a configuración de alimentación simplificada con 1x LM2596 a 5.0V
2026-07-01 Actualizar pines de servomotores a 23, 17, 15 y 13 en firmware y docs
2026-07-01 Reducir frecuencia de bus I2C a 100kHz y agregar escaneo de diagnostico en calibrate_mpu
2026-07-01 Secuenciar arranque de servos en pos_reposo para estabilizar voltaje de bateria
2026-07-01 Corregir NameError de forward reference definiendo establecer_angulo_pata antes de pos_reposo
2026-07-01 Optimizaciones de latencia: no-bloqueante pos_reposo, espera inteligente de stop y GC en segundo plano
2026-07-01 Corregir latencia crítica reduciendo timeout de sonar a 5ms y aplicando mitigación por desconexión en sensor_updater
2026-07-02 Archivamiento y cierre del proyecto: reestructuracion CAD plana, limpieza de imagenes y actualizacion de README para 4-DoF
    [cuerpo_cuadruepdo.stl, eslabon_pata_cuadrupedo.stl, tibia_pata.stl]
2026-07-02 Archivamiento: subir piezas STL definitivas (placa base inferior corrected size y cuerpo/eslabon matches)
    [cuerpo_cuadruepdo.stl, eslabon_pata_cuadrupedo.stl, placa_base_inferior.stl]
2026-07-02 Archivamiento: actualizacion de CodeWiki local (4-DoF) por OpenCode y redireccionamiento de imagen README a assets/
2026-07-02 Archivamiento: actualizacion de render del robot a diseno circular definitivo de 4-DoF

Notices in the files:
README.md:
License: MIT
